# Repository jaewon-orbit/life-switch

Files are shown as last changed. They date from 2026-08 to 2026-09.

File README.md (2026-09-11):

# 💡 Life Switch

Control physical switch in the real world, remotely.

<br>

## 🎥 Demo

Demo video (https://www.youtube.com/watch?v=VIDEO_ID)

<br>

## Why Life Switch?

Lying in my bed, I didn't want to get up just to turn off the lamp. I also wanted to be able to turn it off from outside my home, in case I forgot to switch it off before leaving.

There are still many devices that require physical interaction.<br>
Building this project as a starting point for remotely controlling the analog switches and buttons in our homes.

<br>

## Approach

Most existing ways to control lighting remotely fall into three categories:

- Cutting wires and rewiring the switch into a smart switch
- Cutting external power with a smart plug
- Replacing the bulb with a smart bulb

All three share the same limitation — they can't use the lamp's original physical switch, and they carry wiring risk or require modifying/replacing the product.

Life Switch takes a different approach: a motor-based module attached to the outside of the switch, operating the existing physical switch directly — no rewiring, no bulb replacement.

<br>

## Tech Stack

| Layer | Tech |
|---|---|
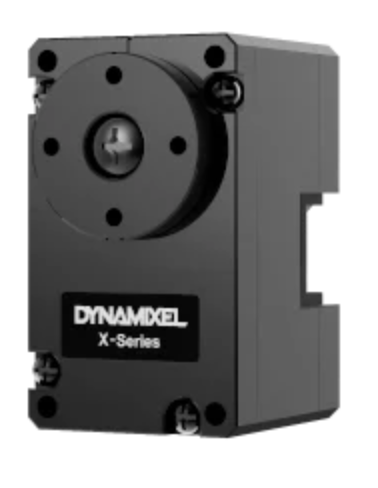
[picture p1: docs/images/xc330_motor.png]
DYNAMIXEL XC330-M288-T
| Motor | DYNAMIXEL XC330-M288-T<br> |
| Motor controller | OpenRB-150 |
| Microcontroller | ESP32 (Wi-Fi) |
| Backend | FastAPI + WebSocket |
| Frontend | GitHub Pages (static) |
| Relay server | VPS + custom domain (`switch.jaewon-orbit.com`) |
| 3D design | Autodesk Fusion |
| Dev/testing tunnel | Cloudflare Tunnel |

<br>

## Architecture

```text
📱 Phone
   ↓ HTTPS
GitHub Pages
   ↓ WSS
☁️ VPS (FastAPI relay)
   ↑ WSS
ESP32
   ↓ UART
OpenRB-150
   ↓
XC330
```

**Why a VPS?**
ESP32 sits behind a home router and can't accept inbound connections. Instead, it connects *outbound* to the VPS, which relays messages between the browser and ESP32 — no port forwarding needed.

**Status sync**
Status isn't polled continuously — it's only requested when needed: on page refresh (via the WebSocket `open` event) or after a toggle command. The server reads the motor's Present Position and compares it against the two known endpoints (`1350` ≈ ON, `1900` ≈ OFF) to decide which state to show.

<br>

## Hardware Assembly

1. Right now, Life Switch remotely controls the physical switch of my IKEA TÅGARP floor lamp.

<div align="center">
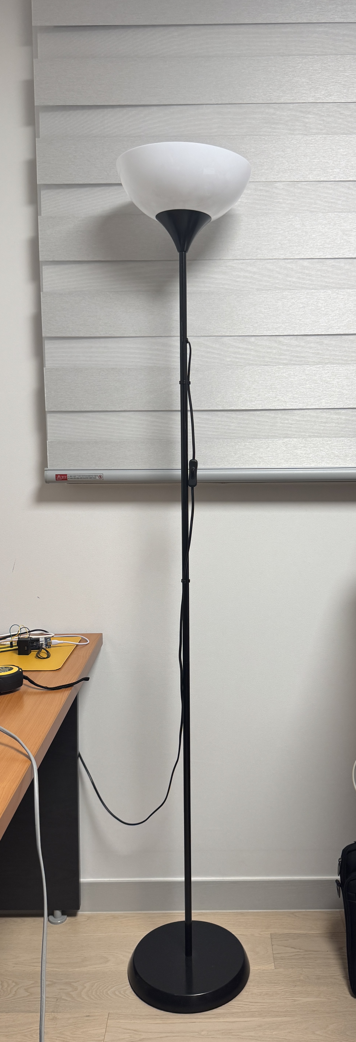
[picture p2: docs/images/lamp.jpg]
TÅGARP floor lamp

</div>
<br>
2. And this is the lamp's inline rocker switch.

<div align="center">
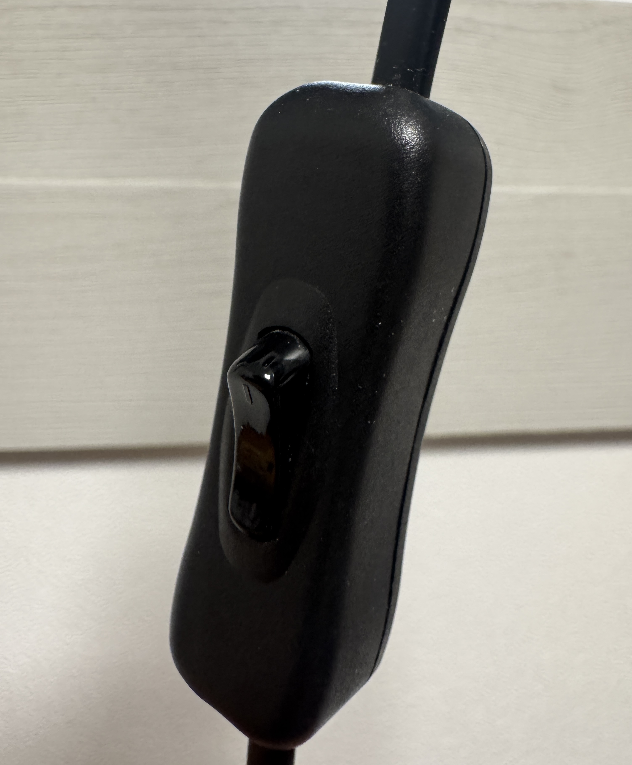
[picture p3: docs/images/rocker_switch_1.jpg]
Lamp's inline rocker switch

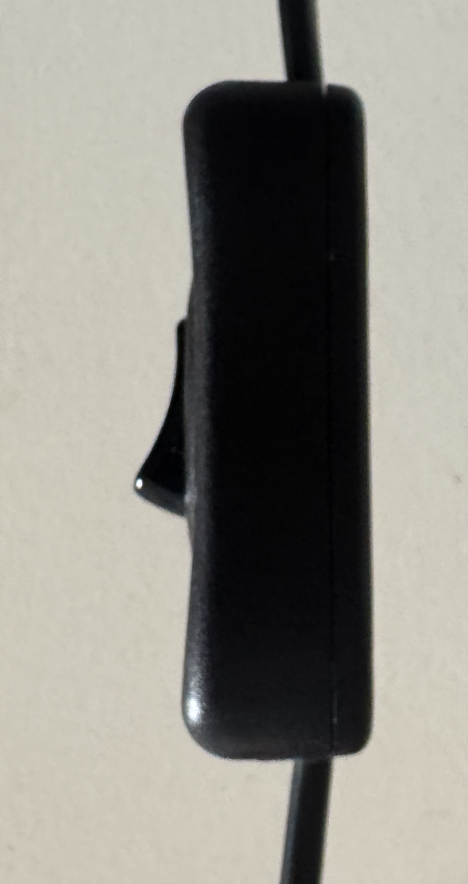
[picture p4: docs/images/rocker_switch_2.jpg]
Lamp's inline rocker switch

</div>
<br>
3. Removed the stock plain horn from the XC330's output disc, and mounted ROBOTIS official XC330 horn (HNX330-N102), onto the output shaft with its center screw.<br>
<a href="./docs/models/XL_XC_330_HORN.stp.zip" download>📦 Download XC330 Horn (HNX330-N102) STP file</a>
<div align="center">
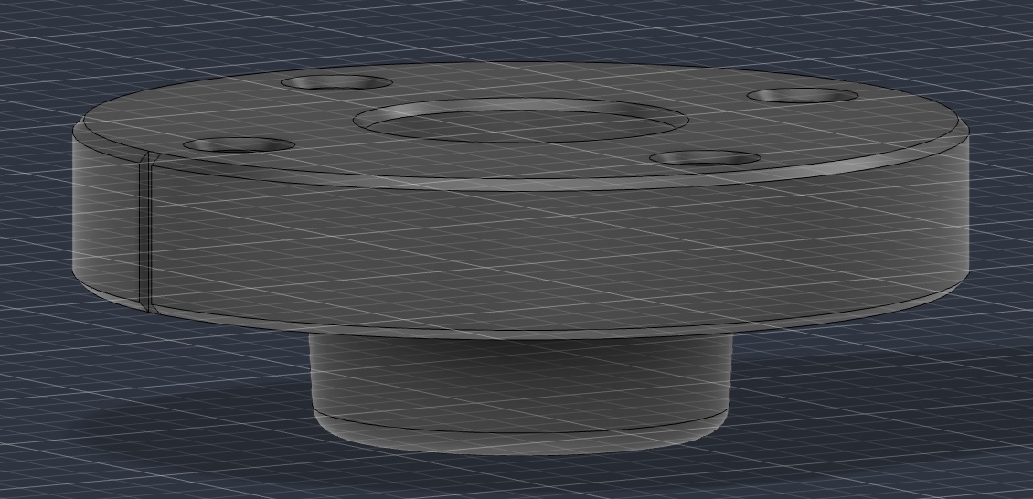
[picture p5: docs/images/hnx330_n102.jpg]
HNX330-N102 horn mounted on the XC330 output shaft

</div>
<br> 
4. Designed a teardrop-shaped horn in Autodesk Fusion, and mounted it onto the HNX330-N102 with M2×6mm screws.<br>
<a href="./docs/models/teardrop_horn.stp.zip" download>📦 Download Teardrop-Shaped Horn STP file</a>
<div align="center">
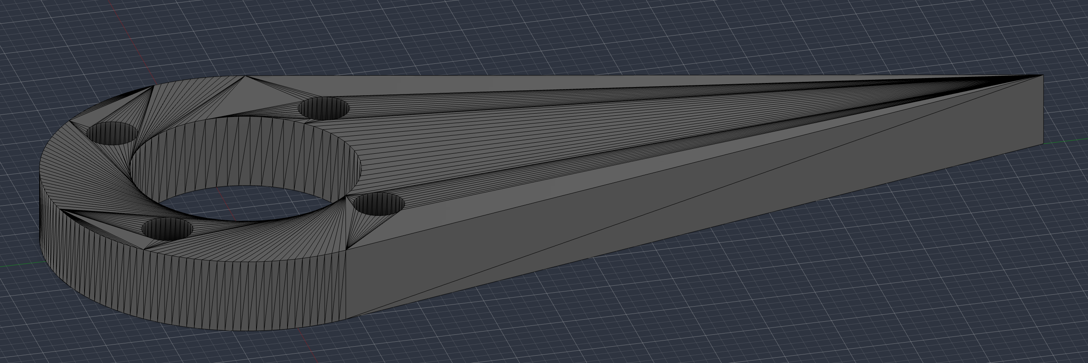
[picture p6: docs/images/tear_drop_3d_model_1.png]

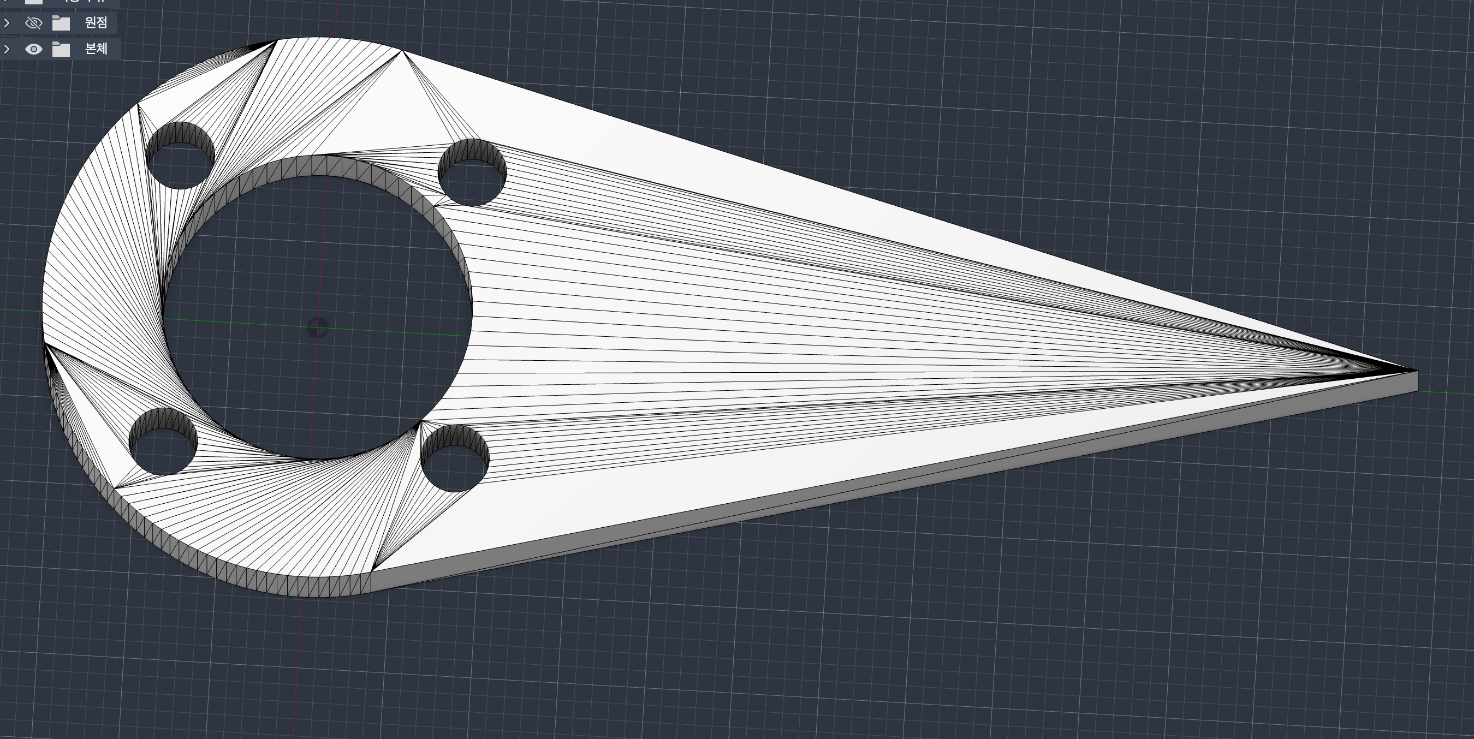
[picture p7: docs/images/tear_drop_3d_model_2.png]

<a href="https://www.youtube.com/watch?v=VIDEO_ID">Horn print, assembly, and test video</a>
</div>
<br> 
5. Attached the motor + horn next to the lamp's inline rocker switch with cable ties, using the horn to physically toggle it.
<div align="center">
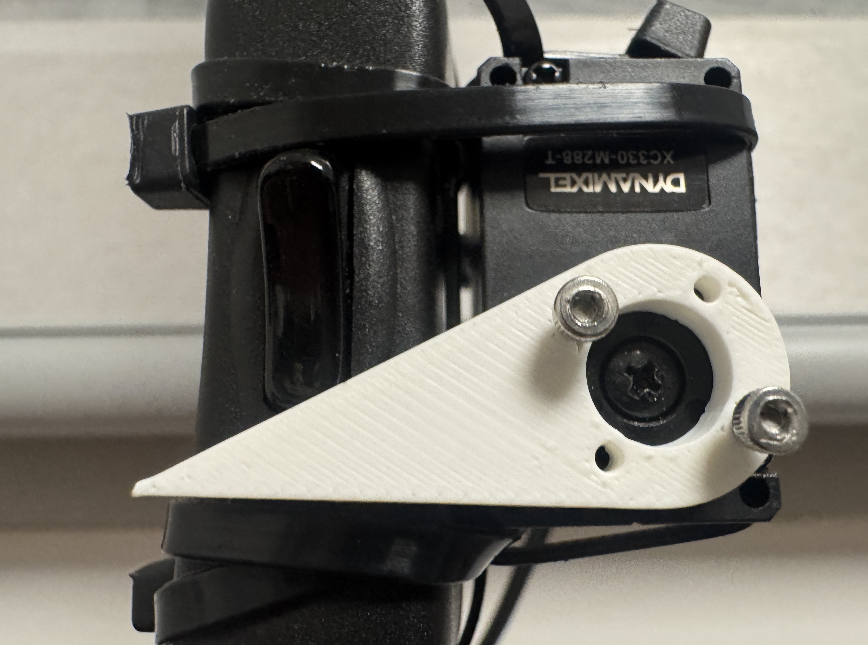
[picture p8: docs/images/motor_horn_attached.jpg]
Motor and horn attached next to the rocker switch

</div>
<br> 
6. Put the ESP32 and OpenRB-150 in a small basket, and cable-tied the basket to the lamp's pole.
<div align="center">
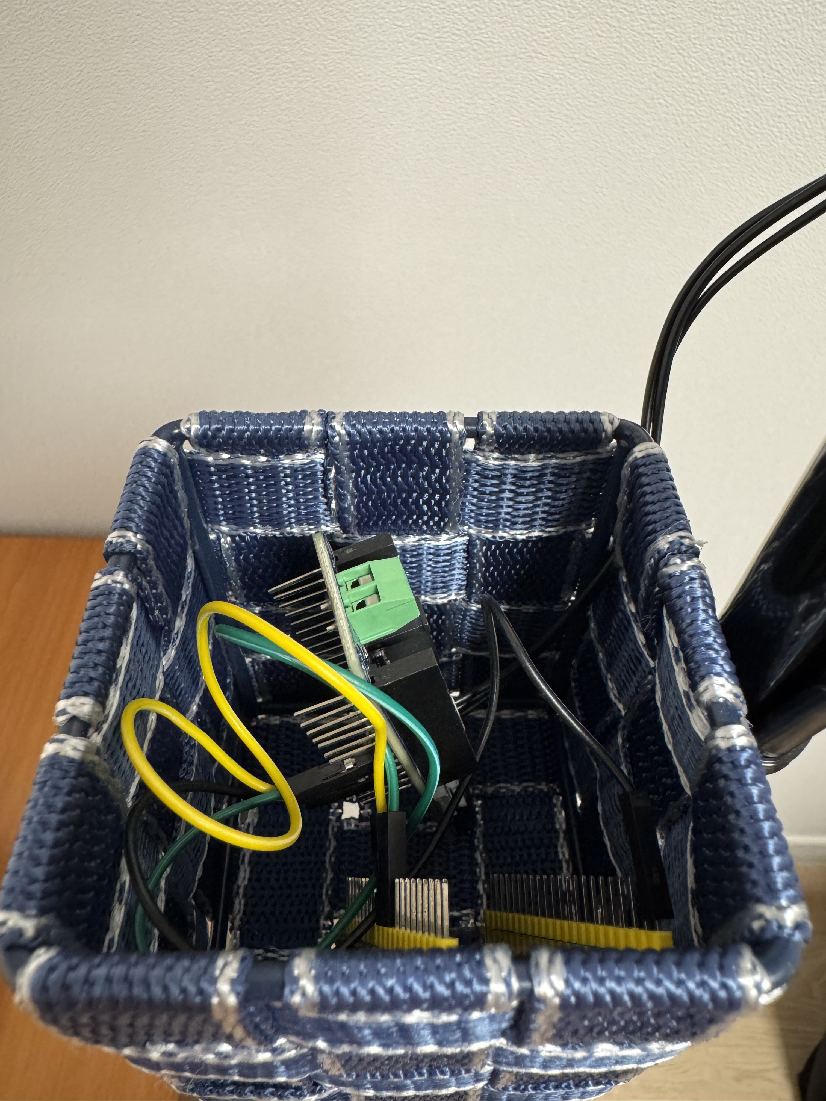
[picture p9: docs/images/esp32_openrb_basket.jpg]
ESP32 and OpenRB-150 inside the small basket

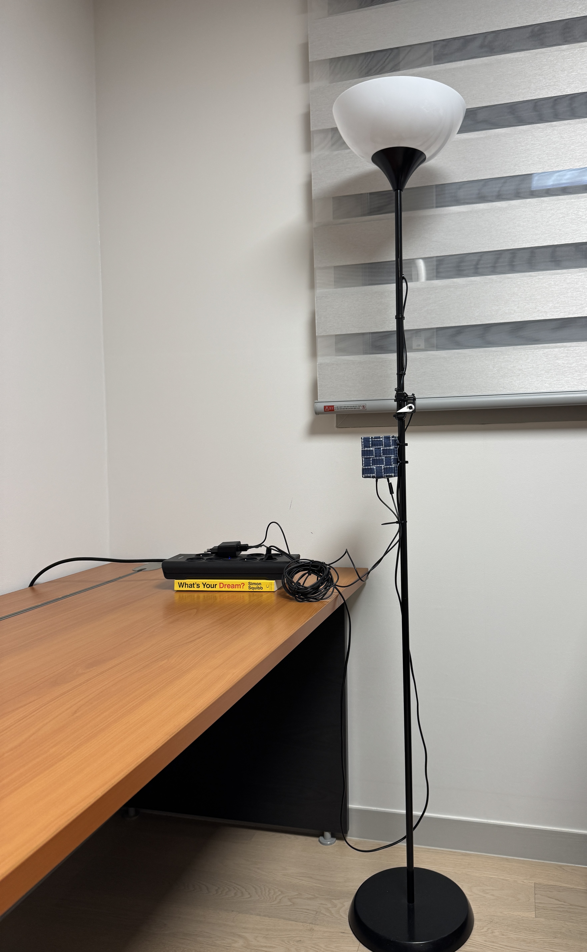
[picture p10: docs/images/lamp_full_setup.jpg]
Floor lamp with the basket tied to the pole

</div>

<br>

## Progress

- **Remote control over LTE** — controlled the motor from a mobile browser over LTE via Cloudflare Tunnel.

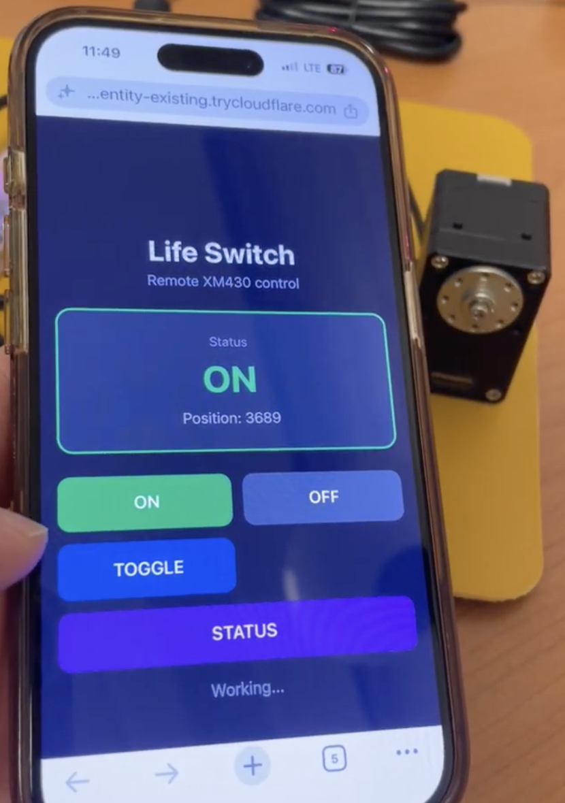
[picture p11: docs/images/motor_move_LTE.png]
Motor controlled remotely over LTE
  

- **Motor: XM430 → XC330** — switched to a smaller motor; refactored control code to use motor profiles instead of hardcoded values.
- **UI revamp** — simplified the UI to show only what the user actually needs.

  | Before | After |
  |:---:|:---:|
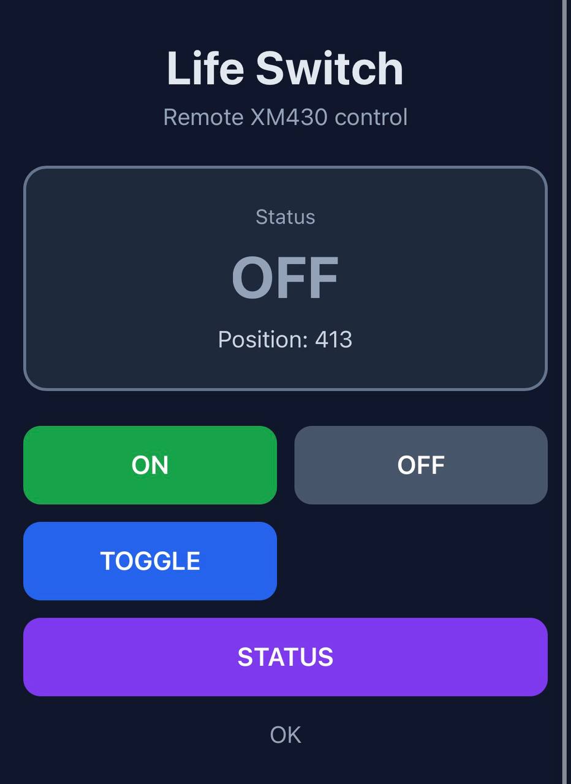
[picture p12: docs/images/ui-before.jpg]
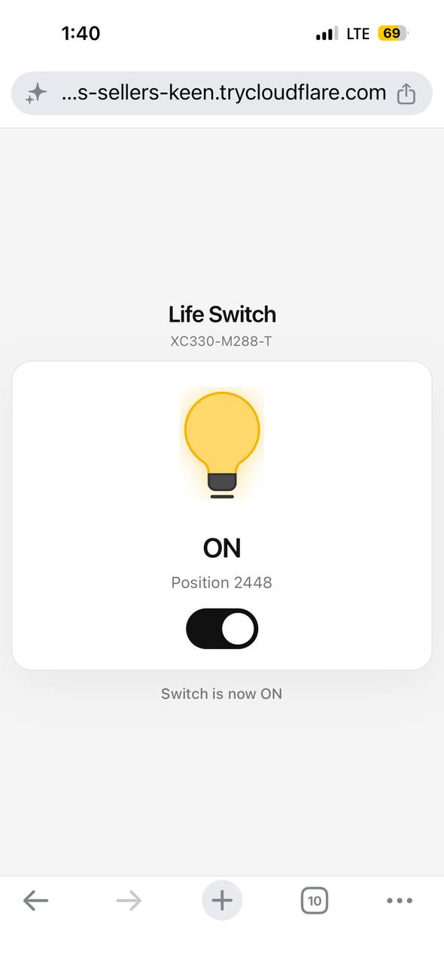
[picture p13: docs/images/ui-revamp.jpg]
  |  |  |

- **Standalone control** — connected ESP32 + OpenRB-150 to control the motor without a PC.

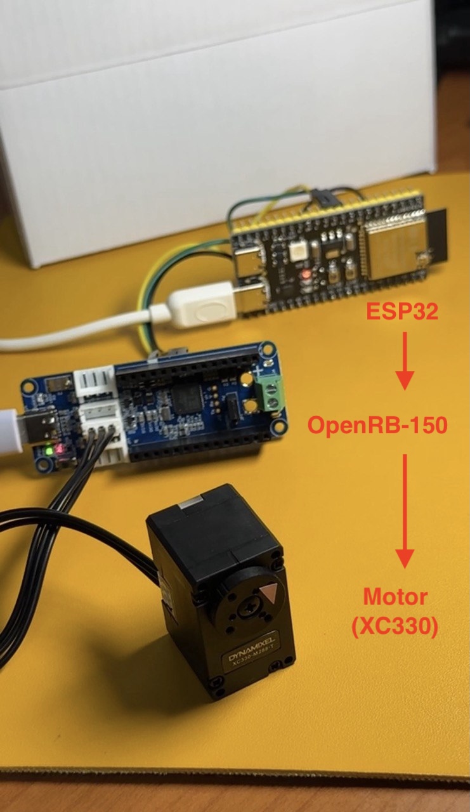
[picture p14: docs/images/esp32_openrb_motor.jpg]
ESP32 and OpenRB motor control setup
  

- **VPS WebSocket relay** — deployed a VPS to relay WebSocket traffic between GitHub Pages and ESP32, avoiding port forwarding.
- **Current-based position control** — switched from position control to current-based position control to protect the motor and the 3D-printed horn.
- **Status sync on refresh** — the browser now requests the real motor position (`STATUS`) whenever the WebSocket connects or a toggle is pressed, instead of relying on a stored default.
- **UI, round 2** — after adding current-based position control and status sync, simplified the browser UI for clearer switch control.
  | Before | After |
  |:---:|:---:|
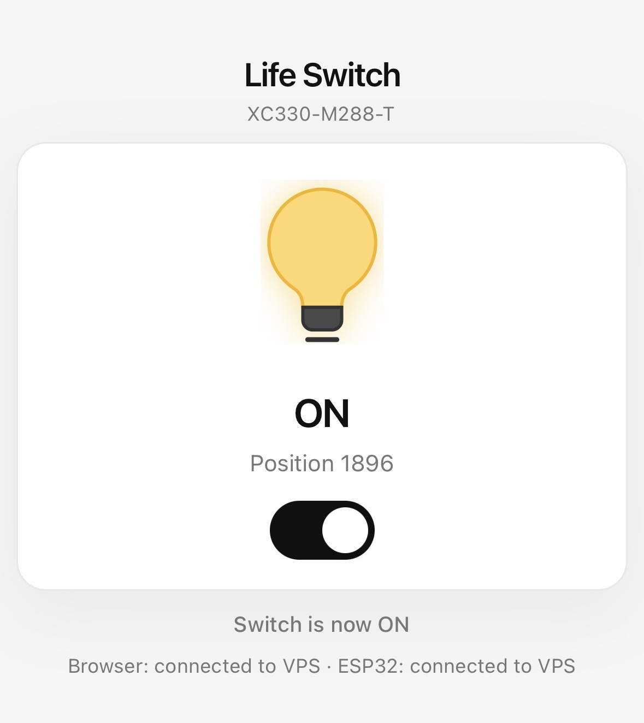
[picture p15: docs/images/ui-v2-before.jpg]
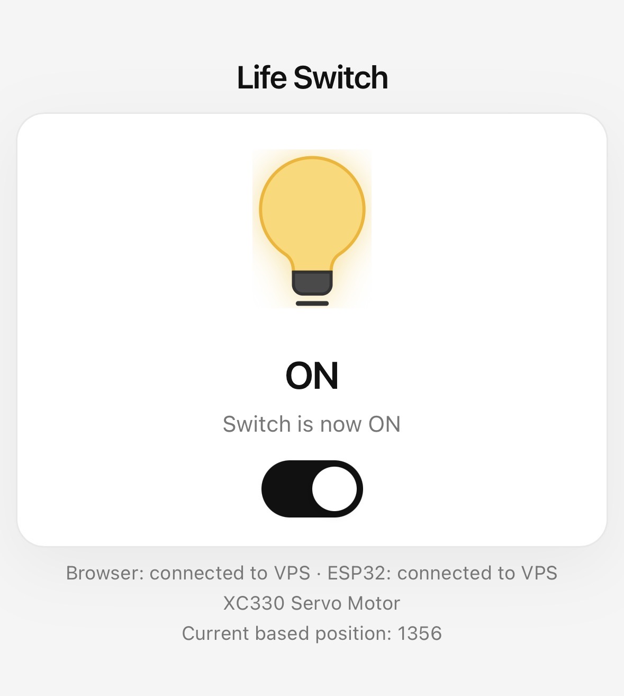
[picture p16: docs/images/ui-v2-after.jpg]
  |  |  |

<br>

## Usage

Open the GitHub Pages site and tap the toggle. That's it — it works the same over LTE or outside the house, thanks to the VPS relay.

<details>
<summary>Legacy: local dev testing via Cloudflare Quick Tunnel</summary>

Used early on to test the browser UI from a phone before the VPS relay existed. Not needed for normal use anymore.

```bash
python -m uvicorn src.server:app --host 127.0.0.1 --port 8000
bash scripts/start_quick_tunnel.sh
```

`cloudflared` prints a random `https://…trycloudflare.com` URL, valid only while the tunnel is running.

</details>

<br>

## Roadmap

### Phase 1 — Motor Control
- [x] Set up Python environment, DYNAMIXEL Wizard 2.0 / SDK, U2D2
- [x] Control the motor with Python scripts, using motor profiles
- [x] Switch from XM430 to XC330-M288T
- [x] Apply current-based position control to protect the motor and horn

### Phase 2 — Remote Control
- [x] Web interface for PC / mobile via FastAPI
- [x] Remote control over LTE via Cloudflare Tunnel
- [x] Revamp the UI for simpler switch control

### Phase 3 — Standalone Control
- [x] ESP32 + OpenRB-150 controlling the XC330
- [x] ESP32 connected to the internet, no port forwarding
- [x] VPS WebSocket relay with a custom domain
- [x] Sync switch status with the real motor position on refresh

### Phase 4 — Physical Integration
- [x] Design a 3D-printed horn for the XC330 (Autodesk Fusion)
- [x] Mount motor + horn on the lamp's inline rocker switch
- [x] Build an ESP32 + OpenRB housing, attach to the lamp pole
- [x] Simplify the UI around current-based position + status sync

<br>

## User Requirements

Enter your Wi-Fi SSID and password in `secret.h` so the ESP32 can connect to Wi-Fi.

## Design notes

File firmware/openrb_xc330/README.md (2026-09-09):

# OpenRB-150 XC330 first-motion test

This sketch validates the first standalone-control link for Life Switch:

`PC (USB-C) -> OpenRB-150 -> XC330-M288-T`

It is configured to match [`src/motor_profiles.py`](../../src/motor_profiles.py):
Protocol 2.0, motor ID `1`, and baudrate `57600`.

## Safety and wiring

1. Disconnect the motor horn from the physical switch for this first test.
2. With power off, connect the XC330's 3-pin TTL cable to any OpenRB DYNAMIXEL
   port. The XC330 is a 5 V TTL model; do not use a 12 V supply.
3. Connect OpenRB-150 to the PC with USB-C. USB may be sufficient for this
   small, unloaded test. For later loaded operation, use a regulated external
   5 V supply through the OpenRB terminal input, with its power-source jumper
   set according to the board manual.

## Arduino IDE setup

1. In **File > Preferences > Additional Boards Manager URLs**, add:

   `https://raw.githubusercontent.com/ROBOTIS-GIT/OpenRB-150/master/package_openrb_index.json`

2. In **Tools > Board > Boards Manager**, install both **Arduino SAMD** and
   **OpenRB**.
3. In **Tools > Manage Libraries**, install **DYNAMIXEL2Arduino**.
4. Select **Tools > Board > OpenRB-150**, select its USB port, open
   `openrb_xc330.ino`, and upload it. If upload fails, double-press the
   OpenRB reset button to enter its bootloader, then upload again.
5. Uploading only starts the command server; it does **not** move the motor.
   Close Serial Monitor if it is open, then run from the project root:

   ```bash
   python scripts/move_openrb_xc330.py --port /dev/ttyACM1
   ```

   The script sends `MOVE`. The board moves to the requested position and then
   disables motor torque. `DONE` confirms the movement completed.

If it prints a ping error, confirm the OpenRB red **DXL** LED lights during the
test, then check cable seating, 5 V power, motor ID `1`, and baudrate `57600`.

## Current-based position control

The sketch uses the XC330's current-based position mode. It retains position
control while setting a torque ceiling on each move. The default ceiling is
400 mA. If the switch does not reliably actuate, test progressively up to
700 mA by sending `CURRENT 400` through `CURRENT 700` over USB serial or from
the ESP32. This setting resets to 400 mA when OpenRB restarts.

## ESP32 UART wiring test

For a non-motor check of the ESP32 link, use the paired sketch in
[`../esp32_openrb_uart_test/`](../esp32_openrb_uart_test/). On OpenRB-150,
`Serial3` uses D13 as RX and D14 as TX; do not use the DYNAMIXEL `Serial1`
port for this link.

## References

- [ROBOTIS OpenRB-150 manual](https://emanual.robotis.com/docs/en/parts/controller/openrb-150/)
- [DYNAMIXEL2Arduino OpenRB serial configuration](https://github.com/ROBOTIS-GIT/Dynamixel2Arduino)

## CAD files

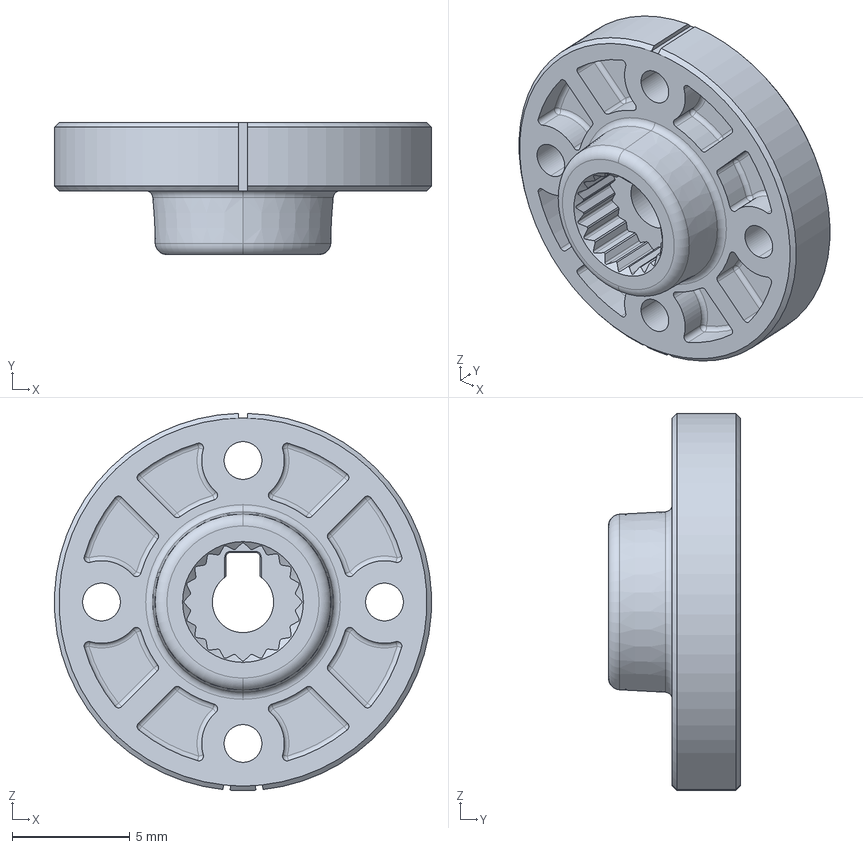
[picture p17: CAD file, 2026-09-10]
docs/models/XL_XC_330_HORN.stp
16.0 x 5.60 x 16.0 mm

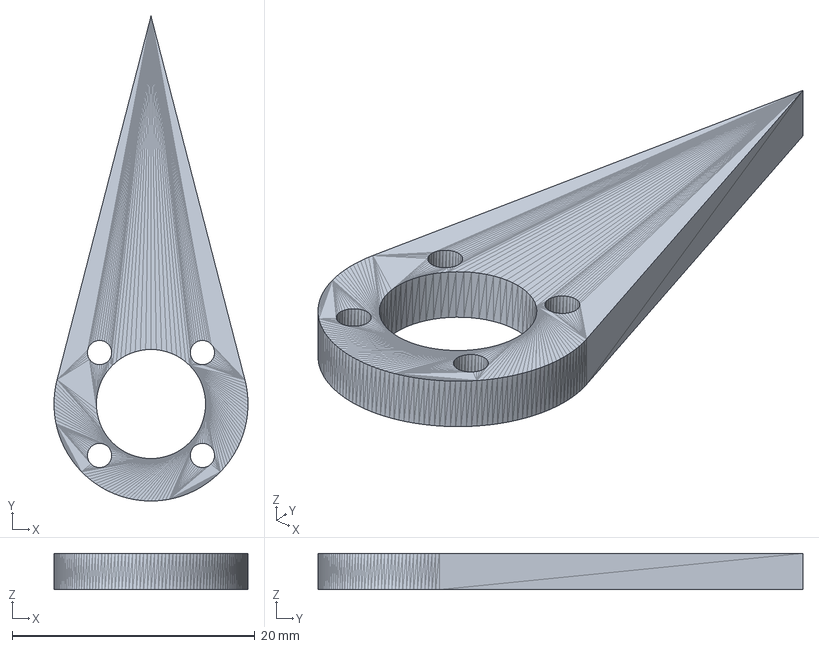
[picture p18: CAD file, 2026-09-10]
docs/models/teardrop_horn.stp
16.0 x 40.0 x 3.00 mm

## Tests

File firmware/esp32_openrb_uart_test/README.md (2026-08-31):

# ESP32-S3 ↔ OpenRB-150 UART test

The test keeps the ESP32 PC console and the OpenRB link electrically separate.

## Exact wiring

| ESP32-S3-WROOM-1-N16R8 header pin | Signal | OpenRB-150 pin | Signal |
| --- | --- | --- | --- |
| GPIO17 | UART1 TX | D13 | Serial3 RX |
| GPIO18 | UART1 RX | D14 | Serial3 TX |
| GND | Ground | GND | Ground |

Both boards use 3.3 V logic. Do not connect a 5 V pin between them.

GPIO17/18 are exposed on the DevKitC-style N16R8 header and are assigned to
UART1 TX/RX. They are not boot strapping pins, USB D-/D+ (GPIO19/20), UART0
COM pins (GPIO43/44), or N16R8 OPI flash/PSRAM pins (GPIO26-32, GPIO33-37).
Arduino-ESP32 routes `HardwareSerial(1)` to this pair through the GPIO matrix.

## VPS WebSocket relay

This sketch opens a persistent outbound WebSocket connection to the FastAPI
endpoint at `/ws/esp32`. The server sends `PING`; the ESP32 replies with
`PONG`. It reconnects every five seconds after a lost connection. Browser
commands (`ON`, `OFF`, `TOGGLE`, and `STATUS`) are forwarded to the OpenRB over
UART, and replies are returned to the VPS. No inbound home-network connection
or port forwarding is required.

1. For a development test, start FastAPI on the VPS:

   ```bash
   python -m uvicorn src.server:app --host 0.0.0.0 --port 8000
   ```

2. In Arduino IDE's Library Manager, install **WebSockets** by Markus Sattler.
3. Copy `secrets.h.example` to `secrets.h`, set `WIFI_SSID` and
   `WIFI_PASSWORD`, and do not commit this file. The sketch connects to
   `wss://switch.jaewon-orbit.com/ws/esp32` on port `443`, verifies the
   Let's Encrypt CA chain, and synchronizes its clock with NTP before starting
   the TLS connection.
4. Upload this sketch to the ESP32 and open its Serial Monitor at 115200 baud.
   It should log `VPS WebSocket connected`, followed by a `PING` and a
   `PONG` about every ten seconds.
5. Visit `https://switch.jaewon-orbit.com/api/esp32/status` to confirm a
   successful connection. It returns `"connected": true` and a recent
   `"last_pong_at"`.
6. Open the browser UI configured for the VPS. It uses `/ws/client`, which
   relays its command to the ESP32 and waits for the OpenRB reply before
   updating the UI.

If the ESP32 loses its VPS connection, it accepts no more remote commands. An
already-started move is bounded by the OpenRB's 10-second move timeout and it
releases motor torque when it completes or times out.

## ESP32 Arduino IDE settings

* **Board:** ESP32S3 Dev Module (or matching ESP32-S3 DevKitC-1)
* **USB CDC On Boot:** Disabled
* **Port:** `/dev/ttyACM0`
* **Serial Monitor:** 115200 baud
* **Flash Size:** 16 MB
* **PSRAM:** OPI PSRAM

Leave USB Mode and Upload Mode at the already-working USB-UART COM values;
they are unrelated to the board-to-board UART.

Upload `esp32_openrb_uart_test.ino`. With OpenRB disconnected, only the
banner and `ESP32 -> OpenRB: PINGING` appear every two seconds. With the
OpenRB sketch below loaded and wired, each send is followed by
`OpenRB -> ESP32: PONG`.

## Minimal OpenRB-150 sketch

`Serial3` is the board-to-board link; D13/D14 must not be connected to an
OpenRB PC console.

```cpp
#include <Arduino.h>

constexpr uint32_t UART_BAUDRATE = 115200;

void setup() {
  Serial.begin(115200);          // Separate OpenRB USB/PC console
  Serial3.begin(UART_BAUDRATE);  // D13 = RX, D14 = TX
}

void loop() {
  static char line[16];
  static size_t length = 0;

  while (Serial3.available() > 0) {
    const char c = static_cast<char>(Serial3.read());
    if (c == '\n') {
      line[length] = '\0';
      if (strcmp(line, "PINGING") == 0) Serial3.print("PONG\n");
      length = 0;
    } else if (c != '\r' && length < sizeof(line) - 1) {
      line[length++] = c;
    } else if (length == sizeof(line) - 1) {
      length = 0;
    }
  }
}
```

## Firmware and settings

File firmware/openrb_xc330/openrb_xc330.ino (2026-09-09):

/*
 * ESP32 -> OpenRB-150 -> XC330-M288-T motor controller.
 *
 * ESP32 wiring (ESP32-S3 DevKitC):
 *   GPIO17 (TX) -> OpenRB D13 (Serial3 RX)
 *   GPIO18 (RX) -> OpenRB D14 (Serial3 TX)
 *   GND        -> OpenRB GND
 *
 * Send one newline-terminated command from the ESP32:
 *   PING             -> PONG
 *   ON               -> move to ON_POSITION
 *   OFF              -> move to OFF_POSITION
 *   TOGGLE           -> move to the opposite position
 *   MOVE <0-4095>    -> move to an explicit position
 *   CURRENT <400-700> -> set the position-control torque limit in mA
 *   STATUS           -> STATUS <current-position>
 *
 * The motor torque is released after each completed move, so it makes one
 * movement and then stops without continuously holding force. Replies are
 * sent back to the ESP32 on Serial3. The USB Serial port is only used for
 * optional debugging. Install the DYNAMIXEL2Arduino library and select the
 * OpenRB-150 board before uploading.
 */

#include <Arduino.h>
#include <Dynamixel2Arduino.h>

constexpr uint32_t DEBUG_BAUDRATE = 115200;
constexpr uint32_t ESP32_BAUDRATE = 115200;
constexpr uint32_t DXL_BAUDRATE = 57600;

constexpr uint8_t DXL_ID = 1;  // XC330-M288-T motor ID
// Keep every commanded position within the physical switch travel range.
// The physical switch is ON at the lower end of this range.
constexpr int32_t ON_POSITION = 1350;
constexpr int32_t OFF_POSITION = 1900;
constexpr int32_t POSITION_MIN = ON_POSITION;
constexpr int32_t POSITION_MAX = OFF_POSITION;
constexpr int32_t POSITION_TOLERANCE = 20;
constexpr uint32_t MOVE_TIMEOUT_MS = 10000;
// Start conservatively. Increase with the CURRENT command only if the switch
// does not reliably actuate; the XC330 reports this value in approximately mA.
constexpr int16_t DEFAULT_GOAL_CURRENT_MA = 400;
constexpr int16_t MIN_GOAL_CURRENT_MA = 400;
constexpr int16_t MAX_GOAL_CURRENT_MA = 700;

constexpr int DXL_DIR_PIN = -1;

HardwareSerial &dxl_serial = Serial1;
Dynamixel2Arduino dxl(dxl_serial, DXL_DIR_PIN);

char command_buffer[32];
size_t command_length = 0;
char usb_command_buffer[32];
size_t usb_command_length = 0;
int16_t goal_current_ma = DEFAULT_GOAL_CURRENT_MA;

void reply(const char *message) {
  Serial3.println(message);
  Serial.print("ESP32 reply: ");
  Serial.println(message);
}

void replyPosition(const char *prefix, int32_t position) {
  char message[48];
  snprintf(message, sizeof(message), "%s %ld", prefix,
           static_cast<long>(position));
  reply(message);
}

bool readPosition(int32_t &position) {
  const float value = dxl.getPresentPosition(DXL_ID);

  if (dxl.getLastLibErrCode() != 0) {
    reply("ERROR READ_POSITION");
    return false;
  }

  position = static_cast<int32_t>(value);
  return true;
}

bool moveTo(int32_t goal) {
  if (goal < POSITION_MIN || goal > POSITION_MAX) {
    reply("ERROR INVALID_POSITION");
    return false;
  }

  dxl.torqueOn(DXL_ID);
  // In current-based position mode this is a torque ceiling, not a command to
  // continuously apply this current. Keep it below the motor Current Limit.
  if (!dxl.setGoalCurrent(DXL_ID, goal_current_ma, UNIT_MILLI_AMPERE)) {
    dxl.torqueOff(DXL_ID);
    reply("ERROR SET_GOAL_CURRENT");
    return false;
  }
  if (!dxl.setGoalPosition(DXL_ID, goal)) {
    dxl.torqueOff(DXL_ID);
    reply("ERROR SET_GOAL");
    return false;
  }

  const uint32_t started_at = millis();
  int32_t position = 0;
  while (millis() - started_at < MOVE_TIMEOUT_MS) {
    if (!readPosition(position)) return false;
    if (abs(goal - position) <= POSITION_TOLERANCE) {
      dxl.torqueOff(DXL_ID);
      replyPosition("DONE", position);
      return true;
    }
    delay(25);
  }

  dxl.torqueOff(DXL_ID);
  reply("ERROR MOVE_TIMEOUT");
  return false;
}

void handleCommand(char *command) {
  while (*command == ' ' || *command == '\t') ++command;
  for (char *p = command; *p != '\0'; ++p) *p = toupper(*p);

  if (strcmp(command, "PING") == 0) {
    reply("PONG");
  } else if (strcmp(command, "ON") == 0) {
    moveTo(ON_POSITION);
  } else if (strcmp(command, "OFF") == 0) {
    moveTo(OFF_POSITION);
  } else if (strcmp(command, "STATUS") == 0) {
    int32_t position = 0;
    if (readPosition(position)) replyPosition("STATUS", position);
  } else if (strcmp(command, "TOGGLE") == 0) {
    int32_t position = 0;
    if (!readPosition(position)) return;
    moveTo(abs(position - ON_POSITION) < abs(position - OFF_POSITION)
               ? OFF_POSITION
               : ON_POSITION);
  } else if (strncmp(command, "MOVE ", 5) == 0) {
    char *end = nullptr;
    const long goal = strtol(command + 5, &end, 10);
    while (*end == ' ' || *end == '\t') ++end;
    if (end == command + 5 || *end != '\0') {
      reply("ERROR INVALID_COMMAND");
      return;
    }
    moveTo(static_cast<int32_t>(goal));
  } else if (strncmp(command, "CURRENT ", 8) == 0) {
    char *end = nullptr;
    const long current = strtol(command + 8, &end, 10);
    while (*end == ' ' || *end == '\t') ++end;
    if (end == command + 8 || *end != '\0' || current < MIN_GOAL_CURRENT_MA ||
        current > MAX_GOAL_CURRENT_MA) {
      reply("ERROR INVALID_CURRENT");
      return;
    }
    goal_current_ma = static_cast<int16_t>(current);
    char message[32];
    snprintf(message, sizeof(message), "CURRENT %d", goal_current_ma);
    reply(message);
  } else {
    reply("ERROR UNKNOWN_COMMAND");
  }
}

void readCommands(Stream &input, char *buffer, size_t &length) {
  while (input.available() > 0) {
    const char received = static_cast<char>(input.read());
    if (received == '\n') {
      buffer[length] = '\0';
      handleCommand(buffer);
      length = 0;
    } else if (received != '\r' && length < sizeof(command_buffer) - 1) {
      buffer[length++] = received;
    } else if (length == sizeof(command_buffer) - 1) {
      length = 0;
      reply("ERROR COMMAND_TOO_LONG");
    }
  }
}

void setup() {
  Serial.begin(DEBUG_BAUDRATE);
  Serial3.begin(ESP32_BAUDRATE);  // OpenRB D13 (RX), D14 (TX)

  dxl.begin(DXL_BAUDRATE);
  dxl.setPortProtocolVersion(2.0);

  if (!dxl.ping(DXL_ID)) {
    Serial.println("ERROR: XC330 not found");
    Serial3.println("ERROR MOTOR_NOT_FOUND");
    return;
  }

  // Operating Mode is EEPROM. Torque must be off before changing it; avoid an
  // unnecessary EEPROM write when the controller is already configured.
  dxl.torqueOff(DXL_ID);
  if (dxl.readControlTableItem(ControlTableItem::OPERATING_MODE, DXL_ID) !=
          OP_CURRENT_BASED_POSITION &&
      !dxl.setOperatingMode(DXL_ID, OP_CURRENT_BASED_POSITION)) {
    Serial.println("ERROR: failed to set current-based position mode");
    Serial3.println("ERROR SET_OPERATING_MODE");
    return;
  }

  delay(300);
  Serial.println("OpenRB XC330 ESP32 controller ready");
  reply("READY");
}

void loop() {
  // Type the same commands in the Arduino IDE Serial Monitor, or send them
  // from the ESP32 over Serial3.
  readCommands(Serial, usb_command_buffer, usb_command_length);
  readCommands(Serial3, command_buffer, command_length);
}

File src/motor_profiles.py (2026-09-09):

"""Motor connection profiles. Add or edit entries here when hardware changes."""

from dataclasses import dataclass
import os

DEFAULT_MOTOR = "A"


@dataclass(frozen=True)
class MotorProfile:
    name: str
    model: str
    device: str
    baudrate: int
    motor_id: int
    off_position: int
    on_position: int
    addr_torque_enable: int
    addr_goal_position: int
    addr_present_position: int
    moving_threshold: int
    power_supply: str = "12V"

    def as_controller_kwargs(self) -> dict:
        return {
            "device": self.device,
            "baudrate": self.baudrate,
            "motor_id": self.motor_id,
            "off_position": self.off_position,
            "on_position": self.on_position,
            "addr_torque_enable": self.addr_torque_enable,
            "addr_goal_position": self.addr_goal_position,
            "addr_present_position": self.addr_present_position,
            "moving_threshold": self.moving_threshold,
        }


# Motor A: XM430-W210 (scan: id=2, baud=4000000, model=1030)
# Motor B: XC330-M288-T (scan: id=1, baud=57600, model=1240)
MOTORS: dict[str, MotorProfile] = {
    "A": MotorProfile(
        name="A",
        model="XM430-W210",
        device="/dev/ttyUSB0",
        baudrate=4000000,
        motor_id=2,
        off_position=400,
        on_position=3700,
        addr_torque_enable=64,
        addr_goal_position=116,
        addr_present_position=132,
        moving_threshold=20,
    ),
    "B": MotorProfile(
        name="B",
        model="XC330-M288-T",
        device="/dev/ttyUSB0",
        baudrate=57600,
        motor_id=1,
        # Constrain switch travel to 1350 <= position <= 1900 (ON is lower).
        off_position=1900,
        on_position=1350,
        addr_torque_enable=64,
        addr_goal_position=116,
        addr_present_position=132,
        moving_threshold=20,
        power_supply="5V",
    ),
}


def get_motor_profile(name: str | None = None) -> MotorProfile:
    motor_name = (name or os.environ.get("MOTOR") or DEFAULT_MOTOR).upper()
    try:
        return MOTORS[motor_name]
    except KeyError as exc:
        valid = ", ".join(sorted(MOTORS))
        raise ValueError(f"Unknown motor {motor_name!r}. Choose one of: {valid}") from exc

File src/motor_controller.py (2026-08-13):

"""Control a Dynamixel motor over U2D2 using the Dynamixel SDK."""

import time

from dynamixel_sdk import *  # noqa: F403

from src.motor_profiles import get_motor_profile

_default = get_motor_profile()
DEVICENAME = _default.device
BAUDRATE = _default.baudrate
PROTOCOL_VERSION = 2.0
DXL_ID = _default.motor_id
OFF_POSITION = _default.off_position
ON_POSITION = _default.on_position

TORQUE_ENABLE = 1
TORQUE_DISABLE = 0


class MotorController:
    def __init__(
        self,
        device: str = DEVICENAME,
        baudrate: int = BAUDRATE,
        motor_id: int = DXL_ID,
        off_position: int = OFF_POSITION,
        on_position: int = ON_POSITION,
        addr_torque_enable: int = _default.addr_torque_enable,
        addr_goal_position: int = _default.addr_goal_position,
        addr_present_position: int = _default.addr_present_position,
        moving_threshold: int = _default.moving_threshold,
    ) -> None:
        self.device = device
        self.baudrate = baudrate
        self.motor_id = motor_id
        self.off_position = off_position
        self.on_position = on_position
        self.addr_torque_enable = addr_torque_enable
        self.addr_goal_position = addr_goal_position
        self.addr_present_position = addr_present_position
        self.moving_threshold = moving_threshold
        self.port_handler = PortHandler(device)
        self.packet_handler = PacketHandler(PROTOCOL_VERSION)
        self._connected = False

    def connect(self) -> None:
        if not self.port_handler.openPort():
            raise RuntimeError(f"Failed to open port: {self.device}")

        if not self.port_handler.setBaudRate(self.baudrate):
            self.port_handler.closePort()
            raise RuntimeError(f"Failed to set baud rate: {self.baudrate}")

        model_number, result, error = self.packet_handler.ping(
            self.port_handler, self.motor_id
        )
        if result != COMM_SUCCESS:
            self.port_handler.closePort()
            raise RuntimeError(
                f"Ping failed: {self.packet_handler.getTxRxResult(result)}"
            )
        if error:
            self.port_handler.closePort()
            raise RuntimeError(
                f"Ping error: {self.packet_handler.getRxPacketError(error)}"
            )

        self._connected = True
        print(f"Connected: {self.device} @ {self.baudrate}, id={self.motor_id}, model={model_number}")

    def close(self) -> None:
        if not self._connected:
            return
        self.disable_torque()
        self.port_handler.closePort()
        self._connected = False

    def __enter__(self) -> "MotorController":
        self.connect()
        return self

    def __exit__(self, exc_type, exc, tb) -> None:
        self.close()

    def enable_torque(self) -> None:
        self._check_comm(
            *self.packet_handler.write1ByteTxRx(
                self.port_handler, self.motor_id, self.addr_torque_enable, TORQUE_ENABLE
            ),
            "enable torque",
        )

    def disable_torque(self) -> None:
        if not self._connected:
            return
        self.packet_handler.write1ByteTxRx(
            self.port_handler, self.motor_id, self.addr_torque_enable, TORQUE_DISABLE
        )

    def get_position(self) -> int:
        position, result, error = self.packet_handler.read4ByteTxRx(
            self.port_handler, self.motor_id, self.addr_present_position
        )
        self._check_comm(result, error, "read position")
        return position

    def move_to(self, goal: int, wait: bool = True) -> int:
        self.enable_torque()
        self._check_comm(
            *self.packet_handler.write4ByteTxRx(
                self.port_handler, self.motor_id, self.addr_goal_position, goal
            ),
            "write goal position",
        )

        if not wait:
            return goal

        while True:
            position = self.get_position()
            if abs(goal - position) <= self.moving_threshold:
                return position
            time.sleep(0.05)

    def on(self) -> int:
        print(f"Switch ON -> position {self.on_position}")
        final = self.move_to(self.on_position)
        print(f"Reached position {final}")
        return final

    def off(self) -> int:
        print(f"Switch OFF -> position {self.off_position}")
        final = self.move_to(self.off_position)
        print(f"Reached position {final}")
        return final

    def is_on(self) -> bool:
        position = self.get_position()
        return abs(position - self.on_position) < abs(position - self.off_position)

    def toggle(self) -> str:
        if self.is_on():
            self.off()
            return "off"
        self.on()
        return "on"

    def _check_comm(self, result: int, error: int, action: str) -> None:
        if result != COMM_SUCCESS:
            raise RuntimeError(
                f"Failed to {action}: {self.packet_handler.getTxRxResult(result)}"
            )
        if error:
            raise RuntimeError(
                f"Failed to {action}: {self.packet_handler.getRxPacketError(error)}"
            )

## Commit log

2026-08-12 Add DYNAMIXEL motor control scripts and controller module.
    Introduce the initial Python implementation for scanning, moving, and toggling the physical switch via a DYNAMIXEL motor over U2D2.
2026-08-12 Add FastAPI web server and browser UI for remote motor control.
    Expose ON/OFF/toggle/status API endpoints and serve a mobile-friendly control page so the switch can be operated from Chrome or Safari on the same Wi-Fi network.
2026-08-13 Add XC330 motor support with dedicated web UI and motor profiles.
    Use motor profiles for motor-specific control so XM430 and XC330 keep separate connection settings and rotation angles across the server and CLI.
2026-08-13 Move motor control table settings into profiles for generic controller support.
    Motor-specific addresses and thresholds now live in motor_profiles.py, so switching between XM430 and XC330 no longer requires controller changes.
    [motor_controller.py, motor_profiles.py, move_motor.py]
2026-08-13 Redirect root URL to the connected motor UI for Cloudflare access.
    Cloudflare tunnel visitors hit / by default, so route them to /xc330 or /xm430 based on which motor is connected instead of always serving the XM430 page.
2026-08-17 Add ESP32 OpenRB UART communication tests
2026-08-17 Add XC330 motor command bridge
2026-08-17 Document LTE and ESP32 motor control
2026-08-30 Add Cloudflare ESP32 remote control relay
2026-08-31 Add VPS WebSocket relay and GitHub Pages deployment
2026-08-31 Use custom domain for WebSocket relay
2026-08-31 Secure ESP32 WebSocket connection
2026-08-31 Document production WebSocket relay
2026-09-09 Use current-based position control for XC330
2026-09-09 Fix XC330 ON and OFF position mapping
    [motor_profiles.py, openrb_xc330.ino]
2026-09-09 Refresh switch status on WebSocket connect
2026-09-09 Reflect XC330 state from motor position
2026-09-10 Revise README for project updates and details
    Updated README.md to reflect recent changes and improvements in the Life Switch project, including a UI revamp, motor change, and new architecture details.
2026-09-10 Revise README with project details and assembly steps
    Updated project description and hardware assembly steps. Changed references from Fusion 360 to Autodesk Fusion.
2026-09-10 Update instructions for ESP32 enclosure
2026-09-10 Revise README with assembly details and demo video
    Updated hardware assembly instructions and added demo video links.
2026-09-10 Add README images and 3D model files (docs/images, docs/models)
    [XL_XC_330_HORN.stp, teardrop_horn.stp]
2026-09-10 Add DYNAMIXEL XC330 motor photo to Tech Stack table
